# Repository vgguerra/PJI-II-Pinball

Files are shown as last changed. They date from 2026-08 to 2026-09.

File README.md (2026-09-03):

# PJI-II Pinball IFSC

Documentação técnica do pinball desenvolvido na disciplina de Projeto Integrador II do curso de
Engenharia de Telecomunicações do IFSC, Campus São José.

Este repositório dá continuidade ao trabalho da turma anterior. O foco aqui é registrar o que
existe, como está ligado, por que foi feito dessa forma e o que ainda falta, de modo que quem
assumir o projeto não precise reconstruir esse entendimento a partir do esquemático.

## Estado atual

O pinball ainda não está funcional. A etapa anterior entregou a arquitetura eletrônica (esquemático
e simulação), as classes básicas de acesso ao hardware em Python e boa parte das peças mecânicas
impressas em 3D. A lógica de jogo não foi implementada.

| Frente | Situação |
|---|---|
| Mecânica (estrutura, flippers, bumpers, injetor) | Parcial: gabinete e playfield decorado prontos, sem componentes instalados |
| Hardware (esquemático e simulação Proteus) | A refazer: o esquemático anterior tem erros estruturais e nada foi montado |
| Software (acesso ao hardware) | Parcial: classes `Raspberry` e `Pcf8574` funcionando |
| Software (lógica do jogo) | Não iniciado |
| Montagem e integração final | Não iniciado |

### A mesa em 13/08/2026

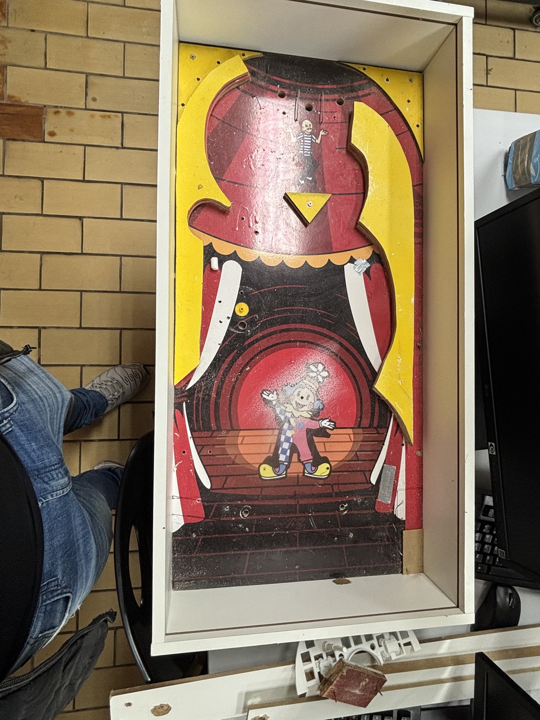
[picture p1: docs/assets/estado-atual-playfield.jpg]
Estado atual do playfield


O gabinete está pronto e o playfield está decorado, com a arte montada em camadas de MDF recortadas.
Estão instaladas as guias de bola brancas, um poste amarelo e alguns reforços, e os furos de montagem
já existem: três maiores no arco superior, dois com anel na região dos flippers e vários de parafuso
ao longo das bordas. A caixa mede 45 x 90 cm.

Não há nenhuma eletrônica instalada: nenhum sensor, solenoide, LED, fio, conector ou placa. A
eletrônica do projeto anterior nunca saiu do papel.

Vale destacar também um erro no esquemático: os três expansores PCF8574 estão com os pinos de
endereço interligados e aterrados, o que os coloca todos em `0x20`. Isso é provavelmente a causa das
falhas intermitentes de comunicação relatadas no relatório anterior. O diagnóstico está em
[Pendências, item P1](docs/09-pendencias-e-roadmap.md).

## Documentação

| Documento | Conteúdo |
|---|---|
| [01. Visão geral](docs/01-visao-geral.md) | Objetivo, escopo, decisões de arquitetura e glossário |
| [02. Arquitetura de hardware](docs/02-arquitetura-hardware.md) | Topologia do sistema, barramentos e alimentação |
| [03. Componentes](docs/03-componentes.md) | Cada componente do projeto, o que é e como é usado |
| [04. Circuitos integrados](docs/04-circuitos-integrados.md) | PCF8574 e L293D em detalhe |
| [05. Pinagem e mapa de I/O](docs/05-pinout.md) | Tabelas pino a pino de todos os CIs |
| [06. Software](docs/06-software.md) | Estrutura do código, API das classes e como evoluir |
| [07. Mecânica](docs/07-mecanica.md) | Peças 3D, modelos de referência e processo |
| [08. Simulação no Proteus](docs/08-simulacao-proteus.md) | Como abrir e rodar a simulação |
| [09. Pendências e roadmap](docs/09-pendencias-e-roadmap.md) | Erros conhecidos e próximos passos |

## Arquitetura em uma figura

```mermaid
flowchart LR
    subgraph SENS["Sensoriamento"]
        SI["3x sensor indutivo<br/>LJ12A3-4-Z/BX<br/>(detecta a bola)"]
        CF["10x fim de curso<br/>KW11-3Z-3<br/>(alvos e posições)"]
    end

    subgraph CTRL["Controle"]
        RPI["Raspberry Pi 4<br/>16 GPIOs de entrada<br/>e barramento I2C1"]
    end

    subgraph EXP["Expansão de I/O"]
        U1["U1, PCF8574"]
        U2["U2, PCF8574"]
        U3["U3, PCF8574"]
    end

    subgraph ACT["Atuação"]
        SL["10x solenoide<br/>(flippers e bumpers)"]
        DRV["3x L293D<br/>driver de potência"]
        LED["12x LED vermelho<br/>(iluminação cênica)"]
    end

    SI -->|nível lógico| RPI
    CF -->|nível lógico| RPI
    RPI <-->|"I2C (SDA/SCL)"| U1
    RPI <-->|"I2C (SDA/SCL)"| U2
    RPI <-->|"I2C (SDA/SCL)"| U3
    U1 --> SL
    U2 --> SL
    U2 --> DRV
    U3 --> DRV
    DRV --> LED
```

A Raspberry Pi lê os sensores diretamente pelos GPIOs, o que mantém a latência baixa (importante
para os flippers), e comanda as cargas através de três expansores PCF8574 no barramento I²C, porque
a Pi não tem GPIOs suficientes para tudo. Os PCF8574 não fornecem corrente para acionar cargas, e é
aí que entram os L293D.

## Ferramentas

`tools/levantar_entradas.py` descobre qual sensor está ligado a qual GPIO, que é a pendência que
trava o resto do projeto. Roda na Raspberry Pi:

```bash
python3 tools/levantar_entradas.py monitor       # imprime toda mudança de estado
python3 tools/levantar_entradas.py identificar   # pede um sensor por vez e grava mapeamento.csv
```

## Organização do repositório

```
PJI-II-Pinball/
├── docs/                   documentação técnica
│   ├── 01-visao-geral.md
│   ├── ...
│   └── assets/             imagens e recortes do esquemático
├── mecanica/
│   └── modelos-3d/         modelos paramétricos em OpenSCAD
├── tools/
│   └── levantar_entradas.py    levantamento do mapeamento sensor para GPIO
├── upstream/
│   └── pinball/            submódulo apontando para o repositório anterior
└── README.md
```

### Sobre o `upstream/pinball`

O trabalho da etapa anterior não foi copiado para cá. Ele está referenciado como submódulo Git
apontando para o repositório original,
[danieCFernandes/pinball](https://github.com/danieCFernandes/pinball), que contém o código-fonte, o
esquemático do Proteus e o relatório final daquela etapa.

Dessa forma o histórico e a autoria originais ficam preservados, e no GitHub a pasta
`upstream/pinball` aparece como um link direto para aquele repositório em vez de abrir uma árvore
de arquivos.

Para clonar este repositório junto com o conteúdo do submódulo:

```bash
git clone --recurse-submodules https://github.com/vgguerra/PJI-II-Pinball.git
```

Se você já clonou sem o `--recurse-submodules`:

```bash
git submodule update --init --recursive
```

Para atualizar a referência caso o repositório original receba novos commits:

```bash
git submodule update --remote upstream/pinball
git add upstream/pinball && git commit -m "Update upstream pinball reference"
```

## Créditos

Etapa anterior (2025/2), projeto de hardware, mecânica e drivers de software: Daniel Cardoso
Fernandes e Roberto da Silva Espindola. Orientação do Prof. Adilson Jair Cardoso.

Instituto Federal de Santa Catarina, Campus São José. Engenharia de Telecomunicações, Projeto
Integrador II.

## Licença

O repositório da etapa anterior declara a MIT License no README, mas não inclui o arquivo `LICENSE`.

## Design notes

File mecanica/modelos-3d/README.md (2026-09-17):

# Modelos 3D

Modelos em [OpenSCAD](https://openscad.org/) para os mecanismos do pinball. Todas as medidas estão
em milímetros e ficam no início de cada arquivo, ou num `parameters.scad` próprio, para serem
ajustadas antes de imprimir.

| Mecanismo | Pasta | Situação |
|---|---|---|
| Flipper | [`flipper`](flipper/) | versão 5, com os dois lados exportados |
| Drop target | [`drop-target`](drop-target/README.md) | peças convertidas dos STL de referência, com simulação do ciclo |
| Plunger handle | [`pinball-plunger`](pinball-plunger/README.md) | impresso e em ajuste de encaixe |

## Flipper

[`flipper/flipper-v5.scad`](flipper/flipper-v5.scad) é a versão atual e reúne o mecanismo completo de
90 mm: pá com canal para borracha, eixo sextavado de 8 mm, base com mancal e batentes, alavanca
inferior, guia frontal, haste de acionamento e botão.

É o único arquivo do flipper: a versão anterior, só do lado esquerdo, foi removida.

O mesmo arquivo atende os dois lados da mesa. Em `lado_flipper`, `"esquerdo"` ou `"direito"` já
ajusta junto as três medidas que mudam com a assimetria do gabinete:

| | esquerdo | direito |
|---|---:|---:|
| Distância lateral | 95,0 mm | 127,0 mm |
| Curso da haste | 110,0 mm | 142,0 mm |
| Posição da guia em X | −55,0 mm | −87,0 mm |

O arquivo abre na montagem, que roda em **View > Animate**. Para inspecionar ou exportar uma peça,
altere `modo_visualizacao` para `"flipper"`, `"eixo"`, `"base"`, `"alavanca"`, `"haste"`,
`"guia_frontal"` ou `"botao"` — as sete peças do mecanismo, cada uma isolada. O modo
`"mesa_impressao"` deita cinco delas na posição de impressão, para fatiar de uma vez; a pá e o eixo
ficam de fora porque pedem orientação própria.

Os STL já exportados estão separados por lado em
[`flipper/export/lado_esquerdo`](flipper/export/lado_esquerdo/) e
[`flipper/export/lado_direito`](flipper/export/lado_direito/), com as sete peças em cada: `alavanca`,
`base`, `botao`, `eixo`, `flipper`, `guia_frontal` e `haste`.

## Drop target

O diretório [`drop-target`](drop-target/README.md) tem as três peças imprimíveis convertidas para
OpenSCAD a partir dos STL de referência, com a caixa envolvente idêntica à do original:

| Peça | Envelope |
|---|---:|
| Gaiola | 40 × 85 × 47,5 mm |
| Alvo | 38,4 × 80 × 12,5 mm |
| Braço do servo | 12 × 64,8 × 4 mm |

Os STL prontos para fatiar ficam em [`drop-target/print`](drop-target/print/README.md) e os originais
que serviram de referência em `drop-target/references`, junto com a foto do conjunto montado.

[`drop-target/simulation`](drop-target/simulation/README.md) monta um módulo completo, com servo
SG90, micro-switch e cordão, para conferir o ciclo antes de repetir o conjunto três vezes: a bola
derruba o alvo, o micro-switch abre, o servo recolhe o braço e o cordão levanta o alvo de volta.
O movimento roda em **View > Animate**.

## Plunger handle

O diretório [`pinball-plunger`](pinball-plunger/README.md) tem o pegador do lançador. O corpo externo
vem do STL de referência sem alteração; o interior foi refeito para a haste real de 6,1 mm e para um
parafuso M4 × 10 que trava a haste.

O furo do parafuso é cônico, de 4,20 mm na entrada a 3,80 mm no fundo: o parafuso começa a descer
solto e vai apertando conforme avança. Essa peça já foi impressa uma vez e as medidas atuais vieram
desse teste.

## Como usar

1. Abra o `.scad` do mecanismo no OpenSCAD.
2. `F5` para visualizar, `F6` para renderizar de verdade.
3. Onde houver animação, ative **View > Animate**; ela usa a variável `$t`.
4. Para exportar, selecione a peça no modo de visualização, renderize com `F6` e use
   **File > Export > Export as STL**.

Pela linha de comando, o que evita abrir a interface:

```bash
openscad --export-format binstl -o saida.stl arquivo.scad
```

## Antes de imprimir

Confira as folgas na sua impressora antes de mandar o conjunto todo. Furo em FDM sai menor que o
nominal, e foi exatamente isso que inutilizou a primeira impressão do plunger: o encaixe desenhado
com 6,00 mm não aceitou uma haste de 6,10 mm. Meça uma peça de teste, compare com o nominal e ajuste
o parâmetro de folga antes de gastar filamento na peça inteira.

As medidas de eixo, espessura do playfield e curso dos mecanismos ainda precisam ser validadas no
protótipo físico.

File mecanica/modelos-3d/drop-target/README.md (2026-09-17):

# Drop target

Conversão para OpenSCAD das três peças do drop target de
[Chris Mitchell](https://www.thingiverse.com/thing:2772610), cujos STL estão em
[`references/`](references/). A foto [`references/image.jpg`](references/image.jpg) mostra o
conjunto montado: **três impressões de cada arquivo**.

Cada peça foi remodelada a partir da malha original, e não apenas importada, para permitir edição
no OpenSCAD. Os STL de referência continuam intactos e podem ser impressos como estão.

| Peça | Arquivo | Envelope | Volume × STL |
|---|---|---|---:|
| Gaiola | [`cage.scad`](cage.scad) | 40 × 85 × 47,5 mm | +0,01 % |
| Alvo | [`target.scad`](target.scad) | 38,4 × 80 × 12,5 mm | +0,00 % |
| Braço do servo | [`servo_stick.scad`](servo_stick.scad) | 12 × 64,8 × 4 mm | −0,04 % |

A caixa envolvente de cada peça convertida é idêntica à do STL correspondente; a diferença de
volume vem apenas da quantidade de facetas nos furos redondos.

## Como ajustar o tamanho peça a peça

Tudo fica em [`parameters.scad`](parameters.scad). Para mudar só uma peça, use a escala dela:

```scad
target_scale = [1, 1.2, 1];   // alvo 20 % mais comprido, gaiola e braço intactos
cage_scale = [1, 1, 1];
servo_stick_scale = [1, 1, 1];
```

Para mudanças que não são de escala, edite as medidas nomeadas: espessura das laterais
(`cage_wall`), vão da gaiola (`cage_slot_width`), largura e comprimento do alvo (`target_width`,
`target_length`), espessura da cabeça (`target_head_thickness`), diâmetro dos furos
(`cage_screw_diameter`, `cage_pin_diameter`, `target_knot_hole_diameter`) e assim por diante. Os
contornos das peças são listas de pontos com nome, então dá para mover um vértice específico sem
mexer no resto.

A quantidade de cada peça também é parâmetro: `cage_count`, `target_count` e `servo_stick_count`,
todos em 3 para reproduzir a foto.

## Como o mecanismo funciona

O alvo corre encostado na face traseira da gaiola. As orelhas de 4,2 mm passam atrás das duas
laterais e é isso que prende o alvo contra a estrutura; a metade dianteira da cabeça entra no vão de
31 mm e faz a guia. O curso é de 30 mm, exatamente a altura da cabeça: em baixo, a base do alvo
encosta na base da gaiola e o topo da cabeça fica rente ao topo da estrutura, ou seja, o alvo some
sob o playfield; em cima, a cabeça aparece inteira. Essa posição foi achada testando peça contra
peça, e é a única em que não há interferência em nenhum ponto do curso.

O microservo é representado na montagem nas coordenadas da gaiola ainda deitada. O eixo fica na
lateral direita, normal à parede, e o corpo do SG90 fica apoiado nessa lateral. O horn e o braço
impresso entram no vão e giram no plano vertical imediatamente abaixo do alvo. Os dois braços
compartilham o mesmo eixo e giram juntos.

O fio é amarrado na ponta longa do braço, a aproximadamente 42 mm do eixo, e sobe até o furo do bloco
do alvo. É essa ponta que sobe junto com o alvo: o braço gira e puxa o fio, levantando o alvo; no
sentido contrário, o alvo desce. Com o fio esticado, a simulação resolve o triângulo a cada quadro
para manter os dois pontos conectados durante os 30 mm de curso.

O dente inferior do alvo encosta na alavanca do microswitch quando o alvo está levantado. Quando a
bola derruba o alvo, o dente desce e o contato abre. A animação segue essa lógica: os três alvos
caem em momentos diferentes e, depois que o terceiro cai, os três servos rearmam o banco junto.

## Vistas

[`drop-target.scad`](drop-target.scad) é o arquivo de abertura. Em `view_mode`:

- `"unidade"`: uma unidade completa em pé, recomendada para conferir o encaixe;
- `"banco"`: três gaiolas encostadas, uma a cada 40 mm, com alvo, servo, chave, fio e braço;
- `"mesa"`: o banco instalado sob o playfield de 450 × 900 mm, com as aberturas dos alvos;
- `"impressao"`: as peças deitadas na quantidade pedida, como saem da impressora;
- `"gaiola"`, `"alvo"`, `"braco_servo"`, `"servo"`: uma peça isolada.

`target_state` aceita `"levantado"`, `"baixado"` e `"animado"`. Para ver o ciclo completo, deixe
`"animado"` e ative **View > Animate** no OpenSCAD. O ritmo fica em `target_drop_times`,
`target_drop_duration`, `reset_start` e `reset_duration`.

O microservo, o microswitch e o playfield são envelopes de referência para conferir encaixe e curso,
não peças para imprimir. As três peças impressas continuam sendo gaiola, alvo e braço.

## O que ficou como estimativa

O conjunto de STL não traz suporte de servo nem nada que fixe a posição relativa das peças. A
posição do alvo (`target_depth_offset`, `target_drop_offset`, `target_travel`) veio de teste de
interferência e não tem folga sobrando. Já a posição do servo (`servo_shaft`), o comprimento do fio
(`string_length`) e o ponto de amarração (`servo_stick_tie`) foram escolhidos para dar o curso
inteiro sem o braço bater no alvo nem na gaiola, o que foi conferido em todo o curso, mas precisam
ser confirmados com o servo real na mão. O mesmo vale para a chave: os dois furos de 2 mm da lateral
direita são os que já existem na peça, mas o alcance da alavanca depende do modelo de microswitch.

A altura em que o banco fica sob a mesa também é escolha de montagem: o topo da estrutura encosta na
face inferior do playfield, e com 10 mm de espessura sobram 20 mm de alvo acima da superfície.

As abas de fixação do servo têm 32,2 mm e o vão entre as laterais tem 31 mm, então elas encostam nas
duas paredes. Pela geometria é o que segura o servo no lugar, mas na montagem real pode ser preciso
lixar as abas ou abrir um rebaixo.

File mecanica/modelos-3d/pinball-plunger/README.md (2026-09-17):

# Plunger handle

Handle do lançador de bolinhas do pinball. O corpo externo vem de
[`ref/Pinball_Plunger_Handle_v5.stl`](ref/Pinball_Plunger_Handle_v5.stl) sem nenhuma alteração; o que
mudou foi o interior, refeito para a haste e o parafuso que vamos usar.

## Arquivos

- [`pinball-plunger-handle.scad`](pinball-plunger-handle.scad): importa a referência e refaz o encaixe interno;
- [`print/pinball-plunger-handle.stl`](print/pinball-plunger-handle.stl): gerado a partir do `.scad`, pronto para fatiar;
- [`ref/Pinball_Plunger_Handle_v5.stl`](ref/Pinball_Plunger_Handle_v5.stl): referência original, não mexer.

## O que a referência tem por dentro

A referência é um desenho em polegadas e não serve para a nossa haste:

| Item | Referência | Nosso arquivo |
|---|---:|---:|
| Envelope | 31,75 × 53,97 × 31,75 mm | igual |
| Diâmetro externo da base | 25,40 mm (1") | igual |
| Furo axial | 13,21 mm (0,52") × 12,75 mm | 7,00 mm × 34,00 mm |
| Furo do parafuso | 2,38 mm (3/32") | cônico, 4,20 → 3,80 mm |
| Assento plano | não tem | 9,00 × 0,60 mm |

## Medidas do nosso arquivo

| Item | Medida |
|---|---:|
| Diâmetro da haste | 6,10 mm (medido na peça) |
| Folga diametral | 0,90 mm |
| Encaixe da haste | 7,00 mm × 34,00 mm |
| Chanfro de entrada | 14,00 mm, 4,00 mm de profundidade |
| Furo do parafuso, entrada | 4,20 mm |
| Furo do parafuso, fundo | 3,80 mm |
| Profundidade do furo | 7,78 mm |
| Assento plano no topo | 9,00 × 0,60 mm |
| Centro do furo do parafuso | 6,35 mm da face de entrada |
| Do assento até a haste | 8,68 mm |
| Parafuso | M4 × 10 mm |
| Volume | 24,7 cm³ |

O furo antigo de 13,21 mm é tapado e o encaixe novo de 7,00 mm é aberto no lugar, com 34 mm de
profundidade. O chanfro de entrada de 14 mm guia a haste e, de quebra, tira da face frontal a borda
do furo original, que era o que sujava a malha na boca do encaixe.

## Como a haste fica presa

O furo do parafuso desce do topo da base e **entra no encaixe da haste**: a ponta do parafuso aperta
a haste contra o fundo do furo, e é esse aperto que prende as duas peças. Na referência o furinho de
3/32" já fazia esse caminho.

**O furo é cônico.** Entra com 4,20 mm no assento e fecha até 3,80 mm lá embaixo, junto ao encaixe
da haste, ao longo de 7,78 mm. São 0,4 mm de fechamento, pouco menos de 3° de ângulo incluso.

Na prática, descendo o parafuso:

| Profundidade | Diâmetro | O que acontece |
|---|---:|---|
| 0 a 3,9 mm | 4,20 a 4,00 mm | desce solto, sem esforço |
| 3,9 mm | 4,00 mm | encosta nas paredes |
| 3,9 a 7,8 mm | 4,00 a 3,80 mm | vai mordendo, aperto crescente |
| 7,8 mm | 3,80 mm | 0,10 mm de interferência no raio |

A partida é fácil e o esforço só aparece no fim, quando já falta pouco: é o oposto do furo estreito
de ponta a ponta, que exigia força máxima logo no primeiro giro e espanava a cabeça. E, diferente do
furo reto de 4,0 mm, aqui existe aperto de verdade nas últimas voltas.

O aperto final é leve — 0,10 mm no raio é cerca de um quarto da profundidade do filete de um M4.
Segura o parafuso no lugar e gera alguma pressão, mas não é o mesmo que uma rosca cheia. Se quiser
mais mordida, baixe `screw_end_diameter` para 3,6 ou 3,5; a entrada continua fácil do mesmo jeito,
porque quem manda na partida é `screw_entry_diameter`.

**Recomendação que continua valendo:** faça uma marca de punção ou um rebaixo raso na haste, no ponto
onde a ponta do parafuso encosta. Com o cone o parafuso já fica firme, mas o que garante que a haste
não escorrega no tranco do plunger é a ponta assentada numa depressão, e não o atrito. Para achar o
ponto: monte a haste até o fundo, desça o parafuso e gire até riscar. Fica a 6,35 mm da face de
entrada.

Do fundo do assento até a haste são 8,68 mm, então o parafuso precisa ser **mais longo que isso**:
um M4 de 10 mm encosta com 1,3 mm de sobra; um de 8 mm não chega a tocar. Essa conta já considera o
pior caso, com a haste empurrada para o fundo do encaixe pelo próprio parafuso.

O assento plano de 9 mm no topo tem duas funções: a ponta do parafuso não escorrega na curvatura da
base ao começar a entrar, e a cabeça de 8 mm de um M4 cabeça panela apoia reta nele. Com parafuso
sem cabeça, o assento serve só de guia.

### Parafuso para comprar

Serve qualquer **M4 × 10 mm**, de preferência com cabeça, que é bem mais fácil de rosquear no
plástico do que um sem cabeça:

- cabeça panela Phillips, avulso, na [Casa do Resistor](https://www.casadoresistor.com.br/parafuso-m4x10-cabeca-panela-philips) — cerca de R$ 0,42 a unidade;
- o mesmo parafuso em pacote de 50 ou 100 peças na [Leroy Merlin](https://www.leroymerlin.com.br/50-pc-parafuso-maquina-cabeca-panela-phillips-m4-4mm-x-10mm_1570865961) e no [Mercado Livre](https://produto.mercadolivre.com.br/MLB-1543465019-parafuso-maquina-cabeca-panela-phillips-m4-x-10mm-100-pecas-_JM);
- se preferir que nada fique para fora, [Allen sem cabeça M4 × 10 de ponta cônica](https://www.mercadolivre.com.br/parafuso-allen-sem-cabeca-m4-x-10--100-pecas--aco-129/up/MLBU747480122): a ponta crava na haste e segura melhor, mas exige chave allen de 2 mm e mais força para entrar.

## Histórico das decisões

O furo do parafuso passou por várias versões antes de chegar no cone, e vale registrar o porquê de
cada uma ter sido descartada:

| Versão | Por que não ficou |
|---|---|
| 3,30 mm reto | medida de furo para macho M4; sem a ferramenta o parafuso não entra |
| Rosca M4 modelada no arquivo | passo de 0,70 mm é fino demais para FDM reproduzir, ainda mais com o furo deitado |
| 3,50 mm reto | força máxima logo no primeiro giro, risco de espanar a cabeça |
| 4,30 → 3,50 mm em dois degraus | resolvia o esforço, mas o degrau não era desejado |
| 4,00 mm reto | entra fácil, mas não gera aperto nenhum |
| **4,20 → 3,80 mm cônico** | partida livre e aperto progressivo — é o que está no arquivo |

Se um dia o aperto do cone não bastar, o caminho mais firme é insert térmico M4: troque
`screw_entry_diameter` e `screw_end_diameter` por um furo reto de 5,6 mm, que cabe nos 7,78 mm de
parede e dá rosca de metal.

## Impressão

Imprimir com a boca do encaixe voltada para cima, para não precisar de suporte dentro do furo.
0,20 mm de camada, 4 paredes e pelo menos 30% de preenchimento.

O encaixe da haste está em 7,00 mm para uma haste de 6,10 mm. A folga é grande de propósito: furo em
FDM sai menor que o nominal, e a primeira impressão, feita com 6,00 mm, não aceitou a haste. A conta
do comprimento do parafuso já leva em conta essa folga. Se quiser apertar o encaixe depois de medir
a peça impressa, mexa em `rod_clearance`.

Para regerar o STL depois de mexer em alguma medida:

```bash
openscad --export-format binstl -o print/pinball-plunger-handle.stl pinball-plunger-handle.scad
```

O `.scad` importa a referência por caminho relativo, então rode o comando de dentro desta pasta.
A renderização leva uns 15 s porque a malha importada tem 22.922 triângulos.

O furo do parafuso é impresso deitado nessa orientação e sai com a leve deformação típica de furo
horizontal em FDM. Medindo a primeira impressão, a máquina fechou só 0,04 mm em relação ao nominal,
então o cone deve sair em torno de 4,16 na entrada e 3,76 no fundo — a partida continua folgada e o
aperto final fica um pouco maior que o desenhado.

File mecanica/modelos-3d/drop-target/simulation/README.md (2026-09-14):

# Simulação de um drop target

`drop-target-simulation.scad` monta **um único módulo completo** para validar o
movimento antes de repetir o conjunto três vezes.

O conjunto usa as peças convertidas a partir dos STL de referência:

- `cage.scad`: gaiola;
- `target.scad`: alvo amarelo;
- `servo_stick.scad`: braço plástico que encaixa no eixo do SG90.

O servo e o micro-switch são envelopes de componentes comerciais. A esfera é
um elemento visual de teste: ela toca a cabeça amarela e inicia a queda. O
OpenSCAD não é um solver físico; por isso o ciclo é cinemático, mas foi
montado com a sequência mecânica do protótipo:

```text
esfera atinge o alvo
  -> alvo desce 30 mm
  -> cordão fica frouxo e o micro-switch libera
  -> servo retorna o braço ao ponto de tração
  -> cordão tensiona e o alvo sobe
```

## Como animar

Abra `drop-target-simulation.scad` no OpenSCAD e use **View > Animate**. A
vista padrão é `view_mode = "modulo"`, que mostra o mecanismo sem o tamanho
do playfield atrapalhar a inspeção. Para conferir a instalação sob a mesa,
use:

```scad
view_mode = "mesa";
```

Estados fixos úteis:

```scad
target_state = "levantado";
target_state = "baixado";
target_state = "animado";
```

Os principais ajustes estão no início do arquivo: `simulation_servo_shaft`,
`arm_rest_angle`, `cord_sag`, `impact_time`, `reset_start`,
`drop_duration`, `release_duration` e `reset_duration`. O eixo foi colocado em
`[6, -54.5, 31]` no sistema da gaiola:
o corpo do SG90 fica deitado dentro da janela lateral esquerda, o eixo aponta
para cima e o braço entra no vão na horizontal. A ponta fina do braço longo
fica à frente e abaixo do alvo, próxima do ponto de amarração. Ao instalar o
primeiro servo real, esse é o primeiro ponto a conferir.

O alvo sobe pela abertura de aproximadamente 30 x 10 mm do playfield de
450 x 900 mm. O mecanismo completo permanece abaixo do playfield; somente a
cabeça amarela atravessa a abertura.

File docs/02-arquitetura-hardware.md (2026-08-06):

[Voltar ao índice](../README.md)

# 02. Arquitetura de hardware

## 2.1 Esquemático completo

O esquemático original está no projeto Proteus `hardware/diagrama-pinball.pdsprj` do repositório
anterior (acessível por [`upstream/pinball`](../upstream/pinball)). A figura abaixo é a exportação
que acompanha aquele repositório.

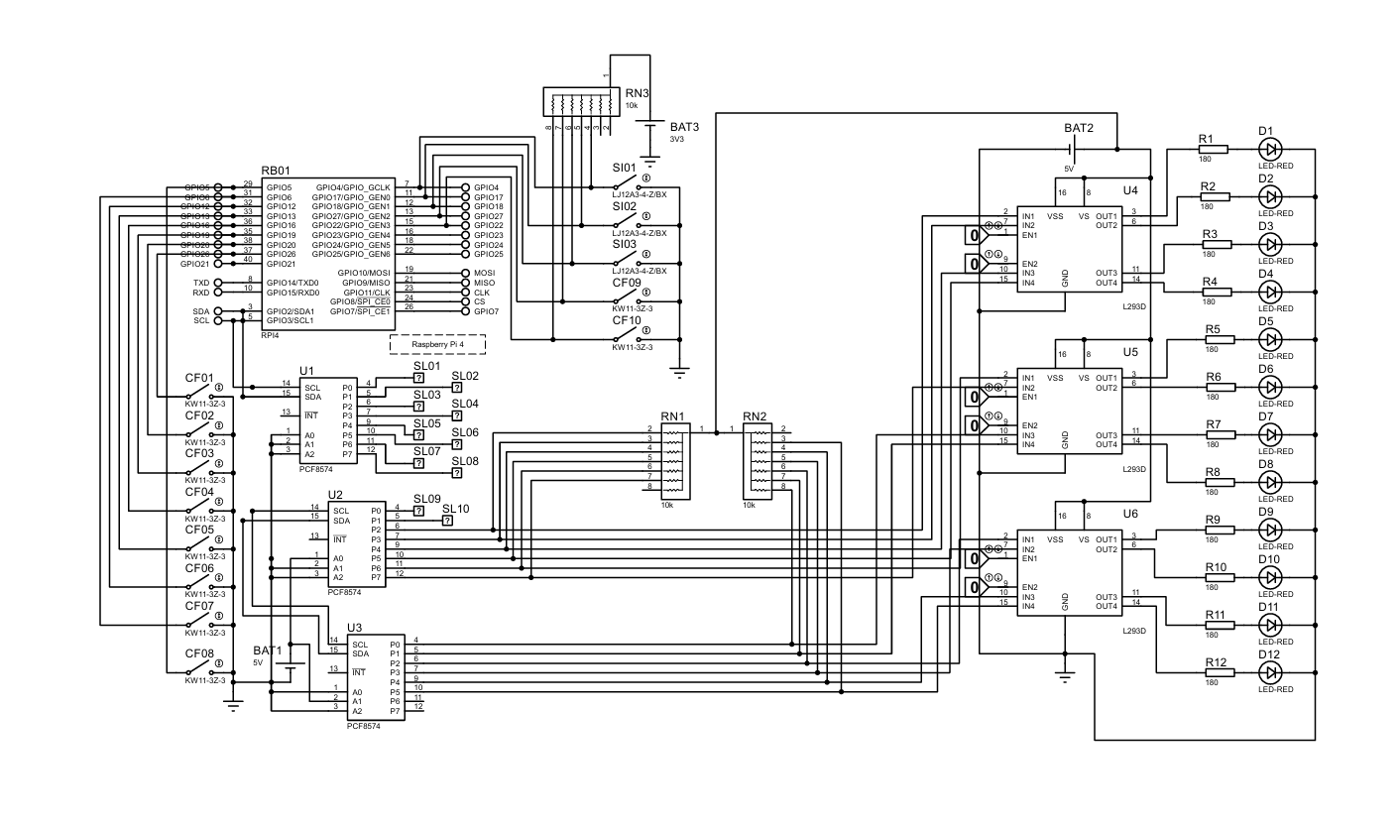
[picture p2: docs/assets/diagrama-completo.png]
Esquemático completo do pinball


O esquemático se lê da esquerda para a direita em quatro blocos: as entradas (chaves de fim de curso
CF01 a CF08), o controlador (RB01, a Raspberry Pi 4) com os sensores do topo, os expansores de I/O
(U1, U2 e U3) e, à direita, o estágio de potência (U4, U5 e U6) com a carga de LEDs.

## 2.2 Topologia do sistema

```mermaid
flowchart TB
    subgraph POT["Alimentação"]
        B3["BAT3, 3V3<br/>referência dos pull-ups<br/>de entrada"]
        B1["BAT1, 5V<br/>lógica dos PCF8574"]
        B2["BAT2, 5V<br/>potência dos L293D"]
    end

    subgraph ENTRADAS["Entradas digitais, 13 sensores"]
        CF1["CF01 a CF08<br/>fim de curso<br/>alvos e botões"]
        SI["SI01 a SI03<br/>sensor indutivo<br/>presença da bola"]
        CF2["CF09 e CF10<br/>fim de curso"]
        RN3["RN3, rede 10k<br/>pull-up"]
    end

    RPI["<b>RB01, Raspberry Pi 4</b><br/>16 GPIOs configurados como entrada<br/>I2C1 em GPIO2 (SDA) e GPIO3 (SCL)"]

    subgraph I2C["Barramento I2C1"]
        U1["<b>U1, PCF8574</b><br/>P0 a P7<br/>8 solenoides"]
        U2["<b>U2, PCF8574</b><br/>P0 e P1: 2 solenoides<br/>P2 a P7: comando dos drivers"]
        U3["<b>U3, PCF8574</b><br/>P0 a P7<br/>comando dos drivers"]
    end

    subgraph SAIDAS["Saídas"]
        SL["SL01 a SL10<br/>10 solenoides"]
        RN12["RN1 e RN2<br/>redes 10k"]
        U456["U4, U5, U6<br/>3x L293D<br/>12 canais de potência"]
        LEDS["D1 a D12 com R1 a R12 (180R)<br/>12 LEDs vermelhos"]
    end

    B3 --> RN3
    RN3 --> SI
    RN3 --> CF2
    CF1 --> RPI
    SI --> RPI
    CF2 --> RPI
    RPI <--> U1
    RPI <--> U2
    RPI <--> U3
    B1 --> U1
    B1 --> U2
    B1 --> U3
    U1 --> SL
    U2 --> SL
    U2 --> RN12
    U3 --> RN12
    RN12 --> U456
    B2 --> U456
    U456 --> LEDS
```

## 2.3 Contagem de I/O

Este é o balanço que justifica a existência dos expansores.

| Função | Quantidade | Onde está ligado |
|---|---|---|
| Sensores de fim de curso | 10 (CF01 a CF10) | GPIO direto da Raspberry Pi |
| Sensores indutivos | 3 (SI01 a SI03) | GPIO direto da Raspberry Pi |
| Solenoides | 10 (SL01 a SL10) | U1 completo, mais P0 e P1 de U2 |
| Canais de LED | 12 (D1 a D12) | U4, U5 e U6, comandados por U2 e U3 |

Somando: 13 entradas nos GPIOs e 22 pontos de saída atendidos por 24 pinos de expansor. A Raspberry
Pi sozinha não daria conta das duas coisas, o que valida a decisão de expandir.

## 2.4 Barramento I²C

A comunicação usa o `I2C1` da Raspberry Pi, disponível nos pinos físicos 3 e 5:

| Sinal | GPIO (BCM) | Pino físico | Destino |
|---|---|---|---|
| SDA | GPIO2 | 3 | Pino 15 (SDA) de U1, U2 e U3 |
| SCL | GPIO3 | 5 | Pino 14 (SCL) de U1, U2 e U3 |

Os três PCF8574 compartilham o mesmo par de fios. O que deveria diferenciá-los é o endereço,
configurado nos pinos de seleção A0, A1 e A2 de cada CI.

> **Atenção.** No esquemático, os pinos A0, A1 e A2 dos três PCF8574 estão todos ligados no mesmo
> nó, e esse nó vai ao terra. Isso faz com que os três CIs respondam no endereço `0x20`
> simultaneamente, o que é um conflito de barramento. O diagnóstico completo e a correção estão em
> [09. Pendências, item P1](09-pendencias-e-roadmap.md). Trate as atribuições de U1, U2 e U3 nesta
> documentação como a intenção do projeto, não como algo que funcione da forma como está desenhado.

O esquemático também não mostra resistores de pull-up externos em SDA e SCL. Na prática a Raspberry
Pi tem pull-ups de 1,8k internos nesses dois pinos, o que costuma ser suficiente para trechos
curtos. Como o cabeamento dentro de uma mesa de pinball é longo e passa perto de solenoides, isso
merece verificação. Ver [P5](09-pendencias-e-roadmap.md).

## 2.5 Alimentação

O esquemático usa três fontes, representadas como baterias por ser um ambiente de simulação.

| Fonte | Tensão | O que alimenta |
|---|---|---|
| BAT1 | 5 V | Alimentação lógica dos três PCF8574 |
| BAT2 | 5 V | Pinos VSS (lógica) e VS (potência) dos três L293D |
| BAT3 | 3,3 V | Referência da rede de pull-up RN3, nas entradas de sensor |

A escolha de 3,3 V para RN3 é correta e importante: os GPIOs da Raspberry Pi trabalham em 3,3 V e
não são tolerantes a 5 V. Puxar uma entrada para 5 V danificaria o SoC.

Já os PCF8574 estão em 5 V, o que cria uma questão de compatibilidade de níveis no barramento I²C
que precisa ser resolvida antes da montagem. Está registrado em
[P4](09-pendencias-e-roadmap.md).

Uma observação sobre dimensionamento: o esquemático não contempla a fonte das solenoides. Solenoides
de pinball tipicamente operam entre 24 V e 48 V e consomem alguns ampères em pulsos curtos. Isso
demanda uma fonte separada, e o estágio de acionamento precisa ser compatível com essa tensão.
Está registrado em [P2](09-pendencias-e-roadmap.md).

## 2.6 Caminho de sinal, entrada

```mermaid
flowchart LR
    A["Bola de metal<br/>ou alvo mecânico"] --> B["Sensor<br/>indutivo ou fim de curso"]
    B --> C["Rede de pull-up<br/>RN3 10k em 3V3<br/>ou pull-up interno"]
    C --> D["GPIO da Raspberry Pi<br/>configurado como entrada"]
    D --> E["GPIO.input()<br/>no Python"]
```

Todos os sensores são ligados em configuração de contato para o terra. O contato em repouso está
aberto, e o pull-up mantém a entrada em nível alto. Quando o sensor atua, ele fecha o caminho para
o terra e a entrada vai a nível baixo.

Consequência prática para o software: a lógica é invertida. `GPIO.input(pin) == 0` significa sensor
acionado, e `== 1` significa sensor em repouso. Isso é o padrão em circuitos de contato seco e é
mais imune a ruído do que a alternativa, mas precisa estar explícito no código.

## 2.7 Caminho de sinal, saída

Há dois caminhos distintos de saída, e a diferença entre eles importa.

O primeiro caminho vai para as solenoides. As saídas P0 a P7 de U1 e P0 e P1 de U2 vão diretamente
para SL01 a SL10. No esquemático essas solenoides aparecem como componentes sem modelo atribuído,
que é a forma do Proteus indicar um símbolo genérico ainda não definido. Ou seja, o estágio de
acionamento das solenoides ainda não foi projetado.

```mermaid
flowchart LR
    A["Software chama<br/>pcf.aciona_saida(n)"] --> B["Escrita I2C<br/>write_byte"]
    B --> C["Pino Pn do PCF8574<br/>vai a nível baixo"]
    C --> D["SL01 a SL10<br/>estágio de potência<br/>ainda não definido"]
    D --> E["Solenoide empurra a bola"]
```

O segundo caminho vai para os LEDs, e este está completo no esquemático. As saídas P2 a P7 de U2 e
P0 a P7 de U3 alimentam as entradas IN1 a IN4 dos três L293D. Cada saída OUT do L293D passa por um
resistor de 180 ohms e acende um LED vermelho.

```mermaid
flowchart LR
    A["Software chama<br/>pcf.aciona_saida(n)"] --> B["Escrita I2C"]
    B --> C["Pino Pn do PCF8574"]
    C --> D["Entrada INn do L293D<br/>via rede RN1 ou RN2"]
    D --> E["Saída OUTn<br/>meia-ponte chaveada"]
    E --> F["Resistor de 180R"]
    F --> G["LED vermelho D1 a D12"]
```

## 2.8 As redes resistivas

O esquemático usa três redes resistivas de 8 elementos com terminal comum, referência `RES8SIPB`.
São encapsulamentos SIP que agrupam oito resistores iguais, usados para economizar espaço quando
várias linhas precisam do mesmo resistor.

| Rede | Valor | Onde está |
|---|---|---|
| RN1 | 10 kΩ | Entre as saídas dos PCF8574 e as entradas dos L293D |
| RN2 | 10 kΩ | Entre as saídas dos PCF8574 e as entradas dos L293D |
| RN3 | 10 kΩ | Pull-up em 3,3 V para os sensores SI01 a SI03, CF09 e CF10 |

A função de RN3 é clara: garantir nível alto definido nas entradas quando o sensor está em repouso.

A função de RN1 e RN2 é definir o nível das entradas dos L293D. Isso faz sentido porque a saída do
PCF8574 é quase bidirecional: ela puxa firmemente para o nível baixo, mas para o nível alto conta
apenas com uma fonte de corrente interna fraca, de cerca de 100 microampères. Um pull-up externo
firma o nível alto e melhora o tempo de subida.

Vale notar que os sensores CF01 a CF08 não têm rede de pull-up externa no esquemático. Eles dependem
do pull-up interno da Raspberry Pi, que o código de fato habilita com `GPIO.PUD_UP`. Funciona, mas
o pull-up interno é da ordem de 50 kΩ, bem mais fraco que os 10 kΩ usados nos outros sensores, o que
os torna mais suscetíveis a ruído captado no cabeamento. Ver [P6](09-pendencias-e-roadmap.md).

## 2.9 Recortes do esquemático

Para facilitar a leitura, os blocos principais estão ampliados abaixo.

### Bloco do controlador e sensores

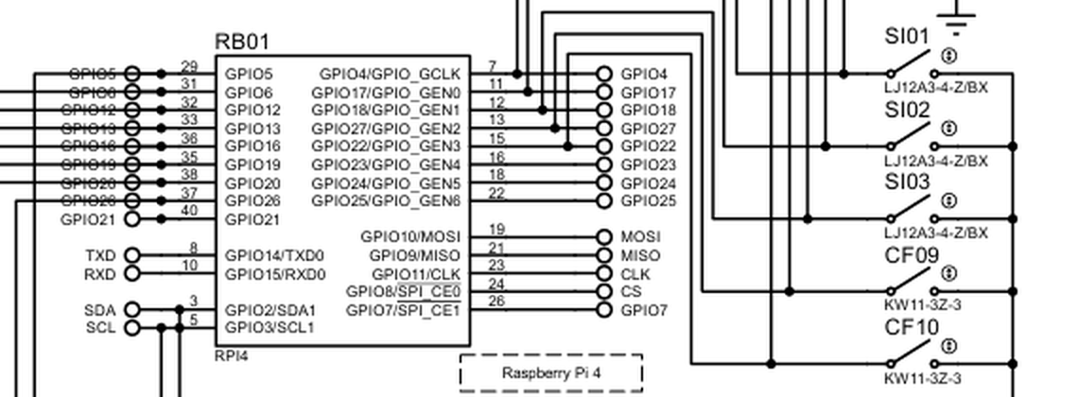
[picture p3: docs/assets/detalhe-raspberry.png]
Detalhe da Raspberry Pi


Aqui se vê a Raspberry Pi 4 (RB01) com os números de pino físico ao lado de cada GPIO, e à direita
os três sensores indutivos SI01 a SI03 e as chaves CF09 e CF10.

### Bloco dos expansores de I/O

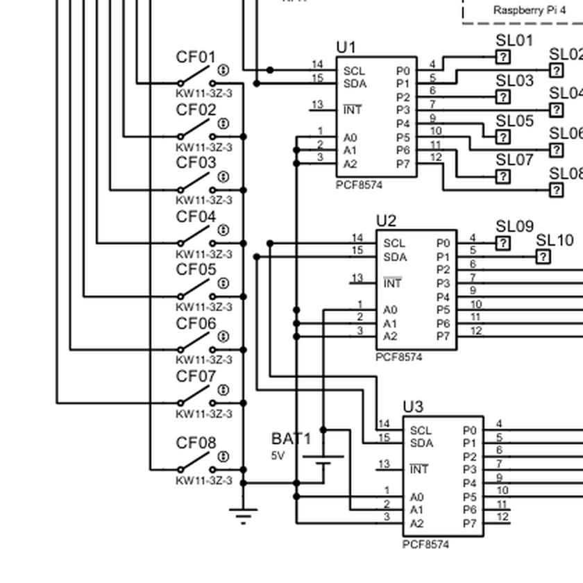
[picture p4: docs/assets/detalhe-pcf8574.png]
Detalhe dos PCF8574


À esquerda as oito chaves de fim de curso CF01 a CF08, cada uma com um terminal ao barramento de
terra e o outro indo para um GPIO. À direita os três PCF8574, com SCL no pino 14, SDA no pino 15,
INT no pino 13 e os pinos de endereço A0, A1 e A2 embaixo. As saídas de U1 vão para SL01 a SL08, e
as duas primeiras de U2 para SL09 e SL10.

### Bloco de potência

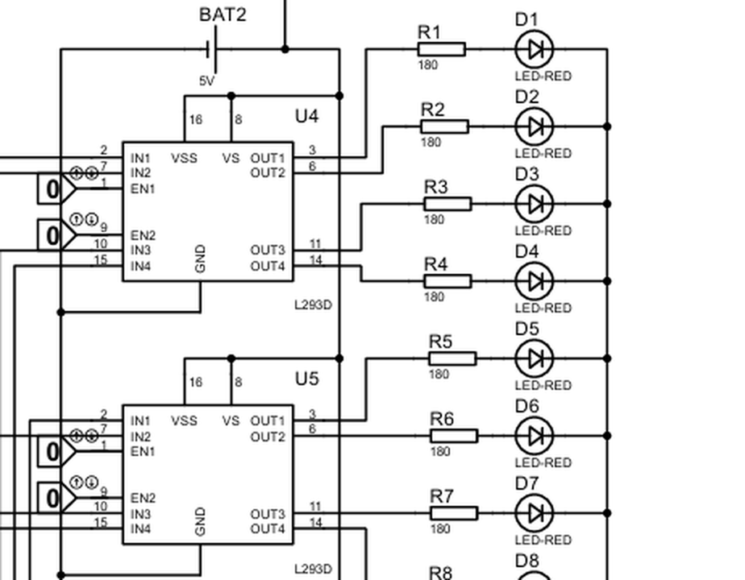
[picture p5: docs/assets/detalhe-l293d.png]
Detalhe dos L293D


Cada L293D recebe 5 V de BAT2 nos pinos 16 (VSS) e 8 (VS), tem GND aterrado, recebe comando em IN1,
IN2, IN3 e IN4, e entrega em OUT1, OUT2, OUT3 e OUT4. Cada saída vai a um resistor de 180 ohms e a
um LED.

Note os blocos com o valor `0` ligados a EN1 e EN2: são atuadores de estado lógico do Proteus,
usados para alternar o sinal manualmente durante a simulação. No hardware real esses pinos de
habilitação precisam de uma origem definida, seja uma saída de expansor ou uma amarração fixa em
nível alto. Ver [P3](09-pendencias-e-roadmap.md).

---

Anterior: [01. Visão geral](01-visao-geral.md) · Próximo: [03. Componentes](03-componentes.md)

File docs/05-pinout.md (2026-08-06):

[Voltar ao índice](../README.md)

# 05. Pinagem e mapa de I/O

Este documento reúne todas as ligações do projeto em forma de tabela. Onde uma informação não pode
ser determinada com certeza a partir do esquemático, isso está indicado de forma explícita em vez de
ser preenchido por suposição.

## 5.1 Raspberry Pi, entradas digitais

O código configura 16 GPIOs como entrada com pull-up interno, na lista definida em
`src/components/Raspberry.py`:

```python
self.entradas = [
    4, 17, 27, 22, 5, 6, 13, 19,
    26, 23, 24, 25, 12, 16, 20, 21
]
```

Esses 16 GPIOs correspondem exatamente aos que aparecem ligados no esquemático, o que confirma que
código e hardware estão de acordo neste ponto. A tabela abaixo cruza numeração BCM, pino físico do
conector de 40 vias e a posição no esquemático.

| GPIO (BCM) | Pino físico | Bloco no esquemático | Observação |
|---|---|---|---|
| GPIO4 | 7 | Superior (sensores) | |
| GPIO5 | 29 | Esquerdo (fim de curso) | |
| GPIO6 | 31 | Esquerdo (fim de curso) | |
| GPIO12 | 32 | Esquerdo (fim de curso) | |
| GPIO13 | 33 | Esquerdo (fim de curso) | |
| GPIO16 | 36 | Esquerdo (fim de curso) | |
| GPIO17 | 11 | Superior (sensores) | |
| GPIO19 | 35 | Esquerdo (fim de curso) | |
| GPIO20 | 38 | Esquerdo (fim de curso) | |
| GPIO21 | 40 | Esquerdo (fim de curso) | |
| GPIO22 | 15 | Superior (sensores) | |
| GPIO23 | 16 | Superior (sensores) | |
| GPIO24 | 18 | Superior (sensores) | |
| GPIO25 | 22 | Superior (sensores) | |
| GPIO26 | 37 | Esquerdo (fim de curso) | |
| GPIO27 | 13 | Superior (sensores) | |

São 16 entradas para 13 sensores, o que deixa 3 GPIOs de reserva.

O esquemático mostra também um GPIO18 desenhado no símbolo da Raspberry Pi, mas ele não aparece na
lista do código e não está ligado a sensor algum. Não faz parte do banco de entradas.

## 5.2 Mapeamento sensor para GPIO

Este é o ponto em que a documentação da etapa anterior não permite conclusão. O esquemático liga os
sensores aos GPIOs por fios que se cruzam ao longo do desenho, sem rótulos de rede (net labels), e a
imagem exportada não permite rastrear com segurança qual fio chega a qual pino.

O que se sabe com certeza:

- Os 13 sensores estão distribuídos entre os 16 GPIOs da tabela anterior.
- CF01 a CF08 estão no bloco esquerdo, cujos fios vão para GPIO5, GPIO6, GPIO12, GPIO13, GPIO16,
  GPIO19, GPIO20, GPIO21 e GPIO26.
- SI01 a SI03, CF09 e CF10 estão no bloco superior, cujos fios vão para GPIO4, GPIO17, GPIO22,
  GPIO23, GPIO24, GPIO25 e GPIO27.

O que precisa ser confirmado abrindo o projeto no Proteus e inspecionando cada nó, ou medindo com
multímetro na montagem física:

| Sensor | Tipo | GPIO | Função no jogo |
|---|---|---|---|
| SI01 | Indutivo | a confirmar | a definir |
| SI02 | Indutivo | a confirmar | a definir |
| SI03 | Indutivo | a confirmar | a definir |
| CF01 | Fim de curso | a confirmar | a definir |
| CF02 | Fim de curso | a confirmar | a definir |
| CF03 | Fim de curso | a confirmar | a definir |
| CF04 | Fim de curso | a confirmar | a definir |
| CF05 | Fim de curso | a confirmar | a definir |
| CF06 | Fim de curso | a confirmar | a definir |
| CF07 | Fim de curso | a confirmar | a definir |
| CF08 | Fim de curso | a confirmar | a definir |
| CF09 | Fim de curso | a confirmar | a definir |
| CF10 | Fim de curso | a confirmar | a definir |

Preencher esta tabela é uma das primeiras tarefas de quem continuar o projeto, e o procedimento
está descrito em [09. Pendências, item P7](09-pendencias-e-roadmap.md).

## 5.3 Raspberry Pi, barramento I²C

| Sinal | GPIO (BCM) | Pino físico | Destino |
|---|---|---|---|
| SDA | GPIO2 | 3 | Pino 15 de U1, U2 e U3 |
| SCL | GPIO3 | 5 | Pino 14 de U1, U2 e U3 |

O barramento usado é o `I2C1`, que precisa estar habilitado no sistema. Ver
[06. Software](06-software.md) para o procedimento.

## 5.4 Raspberry Pi, pinos desenhados mas não usados

O símbolo do Proteus expõe outros pinos que aparecem no desenho sem função atribuída no projeto:

| Sinal | GPIO | Pino físico | Situação |
|---|---|---|---|
| TXD | GPIO14 | 8 | Desenhado, sem uso |
| RXD | GPIO15 | 10 | Desenhado, sem uso |
| MOSI | GPIO10 | 19 | Desenhado, sem uso |
| MISO | GPIO9 | 21 | Desenhado, sem uso |
| CLK | GPIO11 | 23 | Desenhado, sem uso |
| CS | GPIO8 | 24 | Desenhado, sem uso |
| SPI_CE1 | GPIO7 | 26 | Desenhado, sem uso |

Esses pinos ficam disponíveis para expansões. A UART (TXD e RXD) é justamente o caminho natural para
a comunicação com o ESP32 prevista no roadmap, e o SPI ficaria livre para um display de placar.

## 5.5 PCF8574, endereços

### Situação no esquemático

| CI | A2 | A1 | A0 | Endereço resultante |
|---|---|---|---|---|
| U1 | GND | GND | GND | `0x20` |
| U2 | GND | GND | GND | `0x20` |
| U3 | GND | GND | GND | `0x20` |

Os três pinos de seleção dos três CIs estão ligados no mesmo nó, e esse nó vai ao terra. O resultado
é que os três respondem no mesmo endereço, o que impossibilita endereçá-los individualmente.

### Situação no código

O arquivo `src/main.py` instancia um único módulo:

```python
pcf = rasp.adiciona_modulo(0x27)   # endereço 0x27
```

O endereço `0x27` corresponde a A0, A1 e A2 todos em nível alto, o oposto do que o esquemático
desenha. Já o código de teste do relatório e o firmware da simulação usam `0x20`.

Ou seja, há três fontes divergindo entre si. A correção proposta está em
[09. Pendências, item P1](09-pendencias-e-roadmap.md), e a atribuição recomendada é:

| CI | A2 | A1 | A0 | Endereço | Função |
|---|---|---|---|---|---|
| U1 | GND | GND | GND | `0x20` | Solenoides SL01 a SL08 |
| U2 | GND | GND | VDD | `0x21` | Solenoides SL09 e SL10, e comando de driver |
| U3 | GND | VDD | GND | `0x22` | Comando de driver |

## 5.6 PCF8574, mapa de saídas

### U1, solenoides

| Pino do CI | Bit | Saída | Destino |
|---|---|---|---|
| 4 | P0 | SL01 | Solenoide |
| 5 | P1 | SL02 | Solenoide |
| 6 | P2 | SL03 | Solenoide |
| 7 | P3 | SL04 | Solenoide |
| 9 | P4 | SL05 | Solenoide |
| 10 | P5 | SL06 | Solenoide |
| 11 | P6 | SL07 | Solenoide |
| 12 | P7 | SL08 | Solenoide |

### U2, solenoides e comando de driver

| Pino do CI | Bit | Destino |
|---|---|---|
| 4 | P0 | SL09, solenoide |
| 5 | P1 | SL10, solenoide |
| 6 | P2 | Entrada de L293D, via RN1 ou RN2 |
| 7 | P3 | Entrada de L293D, via RN1 ou RN2 |
| 9 | P4 | Entrada de L293D, via RN1 ou RN2 |
| 10 | P5 | Entrada de L293D, via RN1 ou RN2 |
| 11 | P6 | Entrada de L293D, via RN1 ou RN2 |
| 12 | P7 | Entrada de L293D, via RN1 ou RN2 |

### U3, comando de driver

| Pino do CI | Bit | Destino |
|---|---|---|
| 4 | P0 | Entrada de L293D, via RN1 ou RN2 |
| 5 | P1 | Entrada de L293D, via RN1 ou RN2 |
| 6 | P2 | Entrada de L293D, via RN1 ou RN2 |
| 7 | P3 | Entrada de L293D, via RN1 ou RN2 |
| 9 | P4 | Entrada de L293D, via RN1 ou RN2 |
| 10 | P5 | Entrada de L293D, via RN1 ou RN2 |
| 11 | P6 | Entrada de L293D, via RN1 ou RN2 |
| 12 | P7 | Entrada de L293D, via RN1 ou RN2 |

Somando P2 a P7 de U2 com P0 a P7 de U3, há 14 linhas de comando disponíveis para as 12 entradas dos
três L293D. Assim como no caso dos sensores, o esquemático não permite determinar qual linha chega a
qual entrada, porque os fios se cruzam sem rótulo de rede. Essa correspondência precisa ser levantada
no Proteus.

## 5.7 L293D, mapa de ligações

Todos os três CIs seguem o mesmo padrão de alimentação:

| Pino | Nome | Ligação |
|---|---|---|
| 16 | VSS | 5 V, de BAT2 |
| 8 | VS | 5 V, de BAT2 |
| 4, 5, 12, 13 | GND | Terra |

E o mesmo padrão de entradas e saídas:

| Pino | Nome | Origem ou destino |
|---|---|---|
| 1 | EN1 | Atuador de simulação no esquemático, sem origem definida no hardware |
| 9 | EN2 | Atuador de simulação no esquemático, sem origem definida no hardware |
| 2 | IN1 | Saída de PCF8574 |
| 7 | IN2 | Saída de PCF8574 |
| 10 | IN3 | Saída de PCF8574 |
| 15 | IN4 | Saída de PCF8574 |
| 3 | OUT1 | Resistor e LED |
| 6 | OUT2 | Resistor e LED |
| 11 | OUT3 | Resistor e LED |
| 14 | OUT4 | Resistor e LED |

### Correspondência entre saídas e LEDs

| CI | OUT1 | OUT2 | OUT3 | OUT4 |
|---|---|---|---|---|
| U4 | R1 e D1 | R2 e D2 | R3 e D3 | R4 e D4 |
| U5 | R5 e D5 | R6 e D6 | R7 e D7 | R8 e D8 |
| U6 | R9 e D9 | R10 e D10 | R11 e D11 | R12 e D12 |

Todos os resistores R1 a R12 são de 180 ohms, e todos os LEDs D1 a D12 são vermelhos de 5 mm.

Sobre os pinos de habilitação: no esquemático eles estão ligados a atuadores de estado lógico do
Proteus, que servem para alternar o sinal manualmente durante a simulação. No hardware real esses
pinos precisam de uma origem definida. Ver [P3](09-pendencias-e-roadmap.md).

## 5.8 Alimentação

| Fonte | Tensão | Cargas |
|---|---|---|
| BAT1 | 5 V | VDD dos três PCF8574 |
| BAT2 | 5 V | VSS e VS dos três L293D |
| BAT3 | 3,3 V | Comum da rede RN3 |

Todas as referências de terra são comuns, conforme o barramento de terra do esquemático.

Não há fonte prevista para as solenoides, que é uma lacuna do projeto. Ver
[P2](09-pendencias-e-roadmap.md).

## 5.9 Redes resistivas

| Rede | Valor | Elementos | Comum ligado a | Função |
|---|---|---|---|---|
| RN1 | 10 kΩ | 8 | Barramento de saída dos PCF | Pull-up nas linhas de comando dos drivers |
| RN2 | 10 kΩ | 8 | Barramento de saída dos PCF | Pull-up nas linhas de comando dos drivers |
| RN3 | 10 kΩ | 8 | BAT3, 3,3 V | Pull-up nas entradas de sensor |

## 5.10 Referência rápida do conector da Raspberry Pi

Para consulta durante a montagem, com os pinos usados neste projeto destacados na coluna de função.

| Pino | Sinal | Função no projeto | | Pino | Sinal | Função no projeto |
|---|---|---|---|---|---|---|
| 1 | 3V3 | | | 2 | 5V | |
| 3 | GPIO2 | **SDA, I²C** | | 4 | 5V | |
| 5 | GPIO3 | **SCL, I²C** | | 6 | GND | Terra |
| 7 | GPIO4 | **Entrada de sensor** | | 8 | GPIO14 | Livre (UART TX) |
| 9 | GND | Terra | | 10 | GPIO15 | Livre (UART RX) |
| 11 | GPIO17 | **Entrada de sensor** | | 12 | GPIO18 | Livre |
| 13 | GPIO27 | **Entrada de sensor** | | 14 | GND | Terra |
| 15 | GPIO22 | **Entrada de sensor** | | 16 | GPIO23 | **Entrada de sensor** |
| 17 | 3V3 | | | 18 | GPIO24 | **Entrada de sensor** |
| 19 | GPIO10 | Livre (SPI MOSI) | | 20 | GND | Terra |
| 21 | GPIO9 | Livre (SPI MISO) | | 22 | GPIO25 | **Entrada de sensor** |
| 23 | GPIO11 | Livre (SPI CLK) | | 24 | GPIO8 | Livre (SPI CE0) |
| 25 | GND | Terra | | 26 | GPIO7 | Livre (SPI CE1) |
| 27 | GPIO0 | Reservado (EEPROM) | | 28 | GPIO1 | Reservado (EEPROM) |
| 29 | GPIO5 | **Entrada de sensor** | | 30 | GND | Terra |
| 31 | GPIO6 | **Entrada de sensor** | | 32 | GPIO12 | **Entrada de sensor** |
| 33 | GPIO13 | **Entrada de sensor** | | 34 | GND | Terra |
| 35 | GPIO19 | **Entrada de sensor** | | 36 | GPIO16 | **Entrada de sensor** |
| 37 | GPIO26 | **Entrada de sensor** | | 38 | GPIO20 | **Entrada de sensor** |
| 39 | GND | Terra | | 40 | GPIO21 | **Entrada de sensor** |

---

Anterior: [04. Circuitos integrados](04-circuitos-integrados.md) ·
Próximo: [06. Software](06-software.md)

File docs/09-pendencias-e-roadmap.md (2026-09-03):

[Voltar ao índice](../README.md)

# 09. Pendências e roadmap

Este documento lista o que está errado, o que está faltando e em que ordem atacar. Os itens vêm de
três fontes: problemas relatados pela equipe anterior no relatório final, divergências encontradas ao
comparar o esquemático com o código, e lacunas de projeto identificadas na revisão.

## 9.1 Resumo por prioridade

| Item | Assunto | Gravidade |
|---|---|---|
| [P1](#p1-conflito-de-endereço-i2c-nos-três-pcf8574) | Os três PCF8574 no mesmo endereço I²C | Crítico |
| [P2](#p2-acionamento-das-solenoides-não-projetado) | Acionamento das solenoides não projetado | Crítico |
| [P3](#p3-pinos-de-habilitação-dos-l293d-sem-origem) | Habilitação dos L293D sem origem definida | Alto |
| [P4](#p4-compatibilidade-de-níveis-entre-33-v-e-5-v) | Compatibilidade de níveis entre 3,3 V e 5 V | Alto |
| [P5](#p5-pull-up-do-barramento-i2c-não-verificado) | Pull-up do I²C não verificado para cabo longo | Médio |
| [P6](#p6-pull-up-fraco-nos-sensores-cf01-a-cf08) | Pull-up interno fraco em CF01 a CF08 | Médio |
| [P7](#p7-mapeamento-de-sensores-não-documentado) | Mapeamento de sensores não documentado | Médio |
| [P8](#p8-licença-declarada-mas-ausente) | Licença declarada mas sem arquivo | Médio |
| [P9](#p9-repique-de-contato-sem-tratamento) | Repique de contato sem tratamento | Médio |
| [P10](#p10-corrente-dos-leds-abaixo-do-previsto) | Corrente dos LEDs abaixo do previsto | Baixo |
| [P11](#p11-arquivos-3d-originais-não-recuperados) | Arquivos 3D originais não recuperados | Médio |
| [P12](#p12-problemas-menores-de-código) | Problemas menores de código | Baixo |

## P1. Conflito de endereço I2C nos três PCF8574

**Gravidade: crítico.**

### O problema

No esquemático, os pinos A0, A1 e A2 dos três PCF8574 estão ligados no mesmo nó, e esse nó vai ao
terra. Como o endereço do PCF8574 é definido justamente por esses três pinos, os três CIs respondem
no endereço `0x20` simultaneamente.

Isso é um conflito de barramento. Quando o mestre escreve em `0x20`, os três expansores recebem o
mesmo byte e acionam suas saídas juntos. Não há como comandar um sem comandar os outros. Numa
leitura, os três tentam responder ao mesmo tempo e o resultado é indefinido.

### Por que isso importa tanto

O relatório da etapa anterior descreve "falhas intermitentes no reconhecimento de sensores",
"dificuldades na comunicação via barramento I²C" e "inconsistências no funcionamento de módulos
externos", que exigiram "reconfiguração de endereços" e "substituição de componentes". Esses sintomas
são exatamente o que um conflito de endereço produz. É bem provável que este seja o problema raiz por
trás de boa parte do tempo perdido em bancada.

### Como confirmar

Na Raspberry Pi, com o hardware montado:

```bash
i2cdetect -y 1
```

Se aparecer apenas `20` com os três expansores ligados, o conflito está confirmado. Se os três
estivessem corretamente endereçados, apareceriam três endereços distintos.

### A correção

Ligar os pinos de seleção de forma diferente em cada CI. Nível baixo é ligar ao terra, nível alto é
ligar ao VDD do CI.

| CI | A2 | A1 | A0 | Endereço | Função |
|---|---|---|---|---|---|
| U1 | GND | GND | GND | `0x20` | Solenoides SL01 a SL08 |
| U2 | GND | GND | VDD | `0x21` | Solenoides SL09 e SL10, comando de driver |
| U3 | GND | VDD | GND | `0x22` | Comando de driver |

Depois de corrigir o esquemático, o código precisa instanciar os três:

```python
rasp = Raspberry()
pcf_sol1 = rasp.adiciona_modulo(0x20)
pcf_sol2 = rasp.adiciona_modulo(0x21)
pcf_leds = rasp.adiciona_modulo(0x22)
```

### Pendência associada no código

O `src/main.py` usa hoje o endereço `0x27`, que corresponde a A0, A1 e A2 todos em nível alto. Não
corresponde nem ao esquemático nem ao firmware da simulação, que usam `0x20`. As três fontes precisam
ficar coerentes.

## P2. Acionamento das solenoides não projetado

**Gravidade: crítico.**

### O problema

As dez solenoides SL01 a SL10 estão ligadas diretamente aos pinos dos PCF8574, e no esquemático
aparecem como símbolos sem modelo atribuído. Não existe estágio de potência entre o expansor e a
carga.

Um pino de PCF8574 drena no máximo 25 mA. Uma solenoide de flipper de pinball puxa vários ampères no
pulso. Ligar uma na outra destrói o expansor imediatamente.

Há também uma divergência entre documentos: o relatório afirma que os L293D serviriam de driver tanto
para os LEDs quanto para as solenoides, mas o esquemático só implementa o caminho dos LEDs.

### Por que o L293D não resolve

Mesmo que as solenoides fossem ligadas aos L293D, não funcionaria. O L293D entrega 600 mA contínuos e
1,2 A de pico por canal, uma ordem de magnitude abaixo do necessário. E a tensão máxima de 36 V
limita as opções de fonte.

### O que precisa ser projetado

**Estágio de potência.** Um MOSFET de canal N por solenoide, com resistência de condução baixa,
comandado pelo pino do PCF8574 através de um resistor de gate. O MOSFET precisa ser dimensionado para
a corrente de pico com folga. Uma alternativa é usar módulos de driver de alta corrente prontos, o
que reduz o trabalho de projeto de placa.

**Diodo de recuperação.** Obrigatório, em antiparalelo com cada bobina. Ao desligar a solenoide, o
colapso do campo magnético gera um pico de tensão invertida que pode chegar a centenas de volts e
destrói o MOSFET. O diodo dá um caminho para essa corrente. Deve ser de recuperação rápida e
suportar a corrente da bobina.

**Fonte dedicada.** Solenoides de pinball tipicamente operam entre 24 V e 48 V. Essa fonte precisa
ser separada da fonte lógica, e os terras precisam ser unidos em um único ponto para evitar que a
corrente de pulso circule pelo terra da lógica.

**Limite de tempo de acionamento.** Este é o ponto mais importante. Uma solenoide de pinball é
projetada para pulsos de 30 ms a 50 ms. Energizada continuamente, a bobina superaquece e queima em
segundos. O software precisa garantir o desligamento, e é fortemente recomendável ter também uma
proteção em hardware que corte o acionamento independentemente do software, porque uma travada do
programa com a solenoide ligada significa dano físico.

**Desacoplamento.** Capacitores de desacoplamento próximos aos drivers, para absorver o transiente de
corrente do pulso e evitar que a queda de tensão momentânea reinicie a lógica.

### Cuidado com a fonte de 24 V ou 48 V perto da lógica

Com uma fonte dessa tensão no mesmo gabinete, um erro de fiação pode levar 24 V a um GPIO de 3,3 V.
Vale separar fisicamente o cabeamento de potência do de sinal, usar conectores diferentes para os dois
domínios, e conferir com multímetro antes de energizar a Raspberry Pi pela primeira vez.

## P3. Pinos de habilitação dos L293D sem origem

**Gravidade: alto.**

No esquemático, os pinos EN1 e EN2 dos três L293D estão ligados a atuadores de estado lógico do
Proteus, que são componentes de simulação usados para alternar um sinal manualmente clicando com o
mouse. Eles não existem no hardware real.

Sem uma origem definida, esses pinos ficam flutuando na montagem física, e o comportamento das saídas
é imprevisível.

Há duas soluções, e a escolha depende do que se quer.

A mais simples é amarrar EN1 e EN2 ao VCC de 5 V através de um resistor, deixando os canais sempre
habilitados e controlando cada LED apenas pela entrada IN correspondente. Resolve o problema com um
resistor.

A mais flexível é ligar EN1 e EN2 a saídas de PCF8574, o que permite apagar pares de canais de uma
vez, útil para efeitos de luz sincronizados e para um desligamento geral rápido. Custa seis pinos de
expansor, e é preciso verificar se há saídas sobrando.

## P4. Compatibilidade de níveis entre 3,3 V e 5 V

**Gravidade: alto.**

Os GPIOs da Raspberry Pi trabalham em 3,3 V e não toleram 5 V. Aplicar 5 V numa entrada danifica o
SoC de forma permanente. No esquemático há dois pontos que merecem verificação.

**Barramento I²C.** Os PCF8574 estão alimentados em 5 V, por BAT1. Num barramento I²C, tanto SDA
quanto SCL são bidirecionais e em dreno aberto, e o nível alto é definido por quem tem o pull-up. Se
houver um pull-up para 5 V em algum ponto do barramento, esses 5 V chegam ao GPIO da Pi.

Há duas saídas. A mais simples é alimentar os PCF8574 em 3,3 V em vez de 5 V, o que é permitido pelo
CI, que aceita de 2,5 V a 6 V. Isso elimina o problema na origem e é a recomendação. A alternativa é
manter os expansores em 5 V e usar um conversor de nível bidirecional, tipo módulo com MOSFETs BSS138,
entre a Pi e o barramento.

Alimentar em 3,3 V tem uma consequência a considerar: as saídas do expansor passam a fornecer nível
alto de 3,3 V, o que ainda é suficiente para as entradas do L293D, cujo limiar de nível alto é de
cerca de 2,3 V.

**Sensores indutivos.** O LJ12A3-4-Z/BX é especificado para alimentação de 6 V a 36 V, tipicamente
12 V ou 24 V. Se a saída do sensor tiver qualquer caminho interno para a alimentação, esses 24 V
chegam ao GPIO.

O esquemático adota a topologia correta, com a rede RN3 puxando para 3,3 V e o sensor apenas
drenando para o terra. Para que funcione, a saída precisa ser genuinamente coletor aberto. Antes de
ligar na Pi, vale medir a tensão na saída do sensor alimentado, com a linha em aberto e com um
pull-up para 3,3 V, confirmando que ela nunca passa de 3,3 V. Se passar, é necessário um divisor
resistivo ou um optoacoplador.

## P5. Pull-up do barramento I2C não verificado

**Gravidade: médio.**

O esquemático não mostra resistores de pull-up externos em SDA e SCL. A Raspberry Pi tem pull-ups
internos de cerca de 1,8 kΩ nesses dois pinos, que costumam bastar para trechos curtos.

Numa mesa de pinball, porém, o cabeamento é longo e passa perto de solenoides. Cabo longo significa
capacitância parasita maior, o que arredonda as bordas do sinal, e proximidade com bobinas significa
ruído injetado. Se aparecerem erros esporádicos de comunicação, este é um dos suspeitos.

O procedimento recomendado é manter o cabeamento do I²C o mais curto possível, usar par trançado ou
cabo blindado com a malha ao terra em um ponto só, roteá-lo afastado do cabeamento de potência das
solenoides, e verificar o formato das bordas de SCL com osciloscópio se houver instabilidade. Se as
bordas estiverem lentas, acrescentar pull-ups externos de 2,2 kΩ a 4,7 kΩ, lembrando que eles ficam
em paralelo com os internos.

## P6. Pull-up fraco nos sensores CF01 a CF08

**Gravidade: médio.**

As chaves CF01 a CF08 não têm rede de pull-up externa no esquemático. Elas dependem do pull-up
interno da Raspberry Pi, que o código habilita corretamente com `GPIO.PUD_UP`.

O pull-up interno é da ordem de 50 kΩ, bem mais fraco que os 10 kΩ da rede RN3 usada nos outros
sensores. Um pull-up fraco em um fio longo é mais suscetível a ruído captado por acoplamento
capacitivo, e o sintoma é acionamento fantasma: o software registra um alvo atingido sem que a bola
tenha passado.

Como CF01 a CF08 são provavelmente os alvos e os botões dos flippers, ou seja, o que mais importa
para a jogabilidade, vale padronizar. A recomendação é acrescentar uma rede resistiva de 10 kΩ para
3,3 V nessas oito linhas, igual à RN3, e opcionalmente um capacitor de 100 nF de cada linha para o
terra, formando um filtro RC que já ajuda no repique tratado em [P9](#p9-repique-de-contato-sem-tratamento).

## P7. Mapeamento de sensores não documentado

**Gravidade: médio.**

O esquemático liga os 13 sensores aos GPIOs por fios que se cruzam sem rótulos de rede, e a imagem
exportada não permite determinar com segurança qual sensor está em qual GPIO. Também não há indicação
de qual sensor cumpre qual papel no jogo.

Sem essa informação, não é possível escrever a lógica do jogo, porque o software não sabe se o GPIO5
é o botão do flipper esquerdo ou um alvo do canto superior.

Existem dois caminhos para resolver, e o ideal é fazer os dois.

O primeiro é abrir o projeto no Proteus e inspecionar cada nó, anotando a correspondência. É o
caminho mais rápido e independe do hardware estar montado.

O segundo é levantar na bancada, com o hardware ligado, usando o programa de diagnóstico proposto em
[06. Software, seção 6.4](06-software.md#64-o-main-atual). Ele imprime qual GPIO mudou de estado, e
basta acionar um sensor por vez e anotar. Esse método tem a vantagem de refletir a fiação real, que
pode divergir do esquemático.

O resultado deve preencher a tabela da
[seção 5.2](05-pinout.md#52-mapeamento-sensor-para-gpio) e ser codificado no `config/mapa_io.py`
sugerido em [06. Software, seção 6.7](06-software.md#67-estrutura-de-código-sugerida).

## P8. Licença declarada mas ausente

**Gravidade: médio.**

O README do repositório anterior afirma que o projeto está licenciado sob a MIT License e remete a um
arquivo `LICENSE`, mas esse arquivo não existe no repositório.

Juridicamente, código publicado sem licença permanece sob direito autoral integral dos autores, o que
significa que ninguém tem permissão explícita para usar, modificar ou redistribuir, apesar do que o
README diz.

Como o trabalho é acadêmico e a intenção declarada é clara, a resolução é simples: pedir aos autores
originais, Daniel Cardoso Fernandes e Roberto da Silva Espindola, que adicionem o arquivo `LICENSE`
com o texto da MIT ao repositório deles. Enquanto isso não acontecer, este repositório não deve
declarar licença própria sobre material de terceiros.

## P9. Repique de contato sem tratamento

**Gravidade: médio.**

Todo contato mecânico apresenta repique: nos primeiros milissegundos após o fechamento, o contato
abre e fecha várias vezes antes de estabilizar. Nas dez chaves KW11-3Z-3 do projeto isso vai
acontecer.

Sem tratamento, um único toque do jogador no botão do flipper é contado como vários acionamentos. A
pontuação fica errada e a solenoide recebe uma sequência de pulsos em vez de um.

A solução em software é direta, usando o parâmetro `bouncetime` da `RPi.GPIO`:

```python
GPIO.add_event_detect(pino, GPIO.FALLING,
                      callback=trata_sensor,
                      bouncetime=50)   # ignora novas transições por 50 ms
```

Vale notar que essa abordagem também resolve o problema do laço de varredura sem pausa apontado em
[06. Software](06-software.md), porque troca varredura por interrupção.

Um cuidado ao escolher o valor: para o botão do flipper, uma janela grande demais impede o jogador de
acionar em sequência rápida. Entre 20 ms e 50 ms é um ponto de partida razoável, a ajustar em teste.

A solução em hardware, complementar, é um filtro RC de 10 kΩ e 100 nF em cada linha, que dá uma
constante de tempo de 1 ms e já suaviza a maior parte do repique antes de chegar ao GPIO.

## P10. Corrente dos LEDs abaixo do previsto

**Gravidade: baixo.**

Os resistores R1 a R12 são de 180 ohms, valor coerente com um cálculo que supõe 5 V na saída do
driver:

```
R = (5 V - 2 V) / 20 mA = 150 Ω, arredondado para 180 Ω
```

O L293D, porém, perde cerca de 1,4 V internamente no transistor superior, então a tensão que chega ao
resistor é de aproximadamente 3,6 V:

```
I = (3,6 V - 2 V) / 180 Ω ≈ 8,9 mA
```

Os LEDs vão acender com menos da metade da corrente pretendida. Continuam visíveis, mas mais fracos do
que o projeto previa, o que numa mesa de pinball com iluminação ambiente pode ficar insuficiente.

Se o brilho não bastar na montagem, trocar para 82 ohms devolve cerca de 19,5 mA. Vale medir a tensão
real na saída do L293D antes de decidir o valor, porque a queda varia com a corrente.

Como observação de projeto, e não como erro: usar um L293D para acender quatro LEDs é desperdício de
recurso. Um ULN2803, com oito canais Darlington no mesmo tamanho de encapsulamento, cobriria os doze
LEDs com dois CIs em vez de três, com queda de tensão menor e custo mais baixo.

## P11. Arquivos 3D originais não recuperados

**Gravidade: médio.**

O relatório descreve em detalhe as peças mecânicas modeladas e impressas e cita os modelos de
referência usados, mas os arquivos que deram origem às peças da etapa anterior não estão no
repositório. Há um novo modelo editável do flipper em `mecanica/modelos-3d/`, porém ele ainda precisa
ser validado no protótipo físico e não substitui os modelos históricos das demais peças.

Se uma peça quebrar, e o relatório registra que peças quebraram durante os testes, será necessário
reprojetá-la do zero. O trabalho de modelagem, que consumiu boa parte do semestre, está preservado
apenas nas máquinas de quem o fez.

A ação é recuperar os arquivos com os autores originais e versioná-los em
`mecanica/modelos-3d/`, junto com um registro dos parâmetros de impressão que funcionaram: material,
altura de camada, preenchimento e orientação de cada peça.

## P12. Problemas menores de código

**Gravidade: baixo.**

Itens de limpeza no código atual, detalhados em [06. Software](06-software.md).

O `scan()` chama `carregar_entradas()` a cada varredura, reconfigurando os 16 GPIOs milhares de vezes
por segundo. A configuração pertence ao construtor.

O laço do `main.py` não tem pausa, consumindo 100% de um núcleo e produzindo saída ilegível.

O `import time` do `main.py` não é usado, e a variável `pcf` é criada e nunca utilizada.

O `_envia()` imprime a cada escrita, o que deve virar `logging` com nível de depuração.

O arquivo `requeriments.txt` está com o nome grafado errado e está vazio. Deveria ser
`requirements.txt` contendo `RPi.GPIO` e `smbus2`.

O `cleanup()` existe mas nunca é chamado, então os GPIOs ficam no último estado ao encerrar.

Falta um método de leitura na classe `Pcf8574`, e um método para escrever os oito bits de uma vez.

O arquivo `src/components/inductive_sensor.py` está vazio no repositório e deve ser implementado ou
removido.

## 9.2 Ordem de trabalho sugerida

A sequência abaixo respeita as dependências entre as tarefas: cada etapa depende do que vem antes.

```mermaid
flowchart TD
    A["<b>Etapa 1</b><br/>Levantar o mapeamento de I/O<br/>P7"] --> B["<b>Etapa 2</b><br/>Corrigir endereçamento I2C<br/>P1"]
    B --> C["<b>Etapa 3</b><br/>Resolver níveis e habilitação<br/>P3, P4, P6"]
    C --> D["<b>Etapa 4</b><br/>Validar em bancada<br/>LEDs e sensores"]
    D --> E["<b>Etapa 5</b><br/>Projetar acionamento<br/>de solenoide<br/>P2"]
    E --> F["<b>Etapa 6</b><br/>Testar uma solenoide<br/>isolada, com proteção"]
    F --> G["<b>Etapa 7</b><br/>Máquina de estados<br/>do jogo"]
    G --> H["<b>Etapa 8</b><br/>Montagem e ajuste<br/>mecânico"]
    H --> I["<b>Etapa 9</b><br/>Testes de campo<br/>e calibragem"]
```

O raciocínio por trás da ordem é o seguinte.

O mapeamento de I/O vem primeiro porque quase todo o resto depende de saber qual pino é o quê. É
também a tarefa mais barata e pode ser feita sem hardware montado, abrindo o Proteus.

O endereçamento I²C vem em segundo porque nada no lado das saídas funciona de forma controlável
enquanto os três expansores responderem no mesmo endereço.

Níveis e habilitação vêm antes de qualquer teste com hardware energizado, porque errar aqui queima a
Raspberry Pi.

A validação em bancada com LEDs e sensores é o primeiro marco de fato verificável: significa que o
caminho completo, da leitura de um sensor até o acendimento de um LED, está fechado. É um bom ponto de
parada para uma apresentação parcial.

O acionamento das solenoides vem depois, e não antes, porque é a parte que envolve risco de dano e de
projeto novo. Fazer isso com o resto já validado reduz a quantidade de variáveis quando algo der
errado.

Testar uma solenoide isolada antes de montar as dez é o que evita queimar dez bobinas por um erro de
tempo de pulso.

A lógica do jogo vem depois porque depende de todo o hardware responder de forma confiável. Escrever
máquina de estados contra hardware instável gera depuração no lugar errado.

## 9.3 Sobre a migração para ESP32 com RTOS

A conclusão da etapa anterior foi que a arquitetura ideal usa a Raspberry Pi para alto nível e um
ESP32 com RTOS para o tempo real. A recomendação é sólida, com uma ressalva de sequenciamento.

Não vale começar por ela. Migrar para uma arquitetura de dois processadores acrescenta um protocolo de
comunicação, uma segunda toolchain e uma nova classe de bugs de sincronização, tudo isso antes de
existir um pinball que funcione.

O caminho mais seguro é fechar primeiro uma versão jogável só com a Raspberry Pi, tratando os
sensores por interrupção e as solenoides com pulso protegido. Isso valida o hardware, a mecânica e as
regras do jogo com uma variável de menos.

Se, com isso funcionando, a resposta dos flippers se mostrar inconsistente na prática, aí a migração
do laço de tempo real para o ESP32 se justifica, e passa a ser uma otimização com problema conhecido
em vez de uma aposta arquitetural. O caminho de comunicação já está livre: GPIO14 e GPIO15, a UART,
não são usados por nada no projeto atual.

---

Anterior: [08. Simulação no Proteus](08-simulacao-proteus.md)

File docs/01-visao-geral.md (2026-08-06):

[Voltar ao índice](../README.md)

# 01. Visão geral

## 1.1 Objetivo

O projeto nasceu no contexto da Feira de Jogos do IFSC, Campus São José, um evento em que as turmas
de Projeto Integrador desenvolvem jogos físicos interativos. A proposta desta frente foi construir
uma máquina de pinball completa, do zero, usando apenas conhecimentos já adquiridos ao longo do
curso de Engenharia de Telecomunicações.

O pinball serve bem como projeto integrador porque exige, ao mesmo tempo, eletrônica digital
(sensores, atuadores, expansão de I/O, drivers de potência), sistemas embarcados (leitura de
sensores em tempo real, protocolos de comunicação), programação (máquina de estados do jogo,
pontuação, concorrência) e mecânica (estrutura, modelagem 3D, impressão aditiva, ajuste de
mecanismos móveis).

## 1.2 Escopo entregue pela etapa anterior

A equipe anterior, duas pessoas ao longo de um semestre, entregou quatro frentes.

O projeto mecânico inclui a modelagem 3D da mesa e dos obstáculos, com peças já impressas: bumpers,
flippers, injetor de bolas e repositor. Detalhes em [07. Mecânica](07-mecanica.md).

O projeto eletrônico é um esquemático completo feito no Proteus, com Raspberry Pi 4, três expansores
PCF8574, três drivers L293D, sensores e atuadores. Detalhes em
[02. Arquitetura de hardware](02-arquitetura-hardware.md).

A simulação validou a comunicação I²C entre a Raspberry Pi e o PCF8574 dentro do Proteus, antes da
montagem física. Detalhes em [08. Simulação no Proteus](08-simulacao-proteus.md).

Os drivers de software são duas classes Python, `Raspberry` e `Pcf8574`, que abstraem o acesso a
GPIO e I²C. Detalhes em [06. Software](06-software.md).

O que não foi entregue: a lógica do jogo, a integração final e a montagem completa da máquina.

## 1.3 Como um pinball funciona

Entender o fluxo do jogo é o que dá sentido a cada componente eletrônico do esquemático. O ciclo é
o seguinte.

```mermaid
flowchart TD
    Start([Ligar a máquina])
    Attract["Modo atração<br/>LEDs piscando, aguardando jogador"]
    WaitStart{"Jogador<br/>apertou START?"}
    Init["Inicializar partida<br/>pontuação = 0, bola = 1"]
    Launch["Injetor lança a bola<br/>na rampa de entrada"]
    Play["Bola em jogo<br/>flippers ativos"]
    Event{"Sensor<br/>acionado?"}
    Score["Somar pontos,<br/>acender LEDs,<br/>acionar bumper"]
    Drain{"Bola caiu<br/>no dreno?"}
    Count["bola = bola + 1"]
    More{"bola menor ou<br/>igual a 3?"}
    Over["Fim de jogo<br/>exibir pontuação"]

    Start --> Attract --> WaitStart
    WaitStart -- Não --> Attract
    WaitStart -- Sim --> Init --> Launch --> Play
    Play --> Event
    Event -- Sim --> Score --> Play
    Event -- Não --> Drain
    Play --> Drain
    Drain -- Não --> Play
    Drain -- Sim --> Count --> More
    More -- Sim --> Launch
    More -- Não --> Over --> Attract
```

Mapeando cada etapa para o hardware:

| Etapa do jogo | Componente responsável |
|---|---|
| Detectar que a bola passou por um ponto | Sensor indutivo `LJ12A3-4-Z/BX` |
| Detectar que a bola bateu num alvo | Fim de curso `KW11-3Z-3` |
| Ler o botão START e posições de mecanismos | Fim de curso `KW11-3Z-3` |
| Empurrar a bola (flipper, bumper, injetor) | Solenoide acionada via `PCF8574` |
| Iluminação cênica e feedback visual | LED vermelho acionado via `L293D` |
| Contar pontos e decidir o que acontece | Software na Raspberry Pi 4 |

## 1.4 Decisões de arquitetura e o porquê

**Raspberry Pi 4 como cérebro.** Roda Python direto, tem I²C nativo, facilita a depuração e abre
caminho para uma interface gráfica de placar mais adiante.

**Expansores PCF8574 no barramento I²C.** A Pi oferece cerca de 26 GPIOs úteis, e o pinball precisa
de mais de 40 pontos de I/O entre sensores, solenoides e luzes. Cada PCF8574 acrescenta 8 I/Os
usando apenas dois fios do barramento.

**Sensores ligados direto no GPIO, não via PCF8574.** A razão é latência. O flipper precisa
responder em milissegundos ao comando do jogador, e uma transação I²C acrescentaria atraso e jitter
no caminho crítico. Por isso os 13 sensores foram para GPIOs dedicados.

**Drivers L293D para as cargas.** O PCF8574 fornece corrente da ordem de poucos miliampères por
pino, insuficiente para acionar LEDs com brilho adequado e muito abaixo do necessário para
solenoides. O L293D resolve isso funcionando como estágio de potência.

**Migração planejada para RTOS em ESP32.** Python rodando sobre Linux não garante o determinismo
temporal que os flippers exigem. A conclusão da etapa anterior foi que a Pi deve cuidar da lógica
de alto nível e um microcontrolador com RTOS deve cuidar do tempo real. Ver
[09. Pendências e roadmap](09-pendencias-e-roadmap.md).

## 1.5 Glossário

| Termo | Significado |
|---|---|
| Flipper | O batedor acionado pelo jogador para rebater a bola |
| Bumper | Obstáculo circular que repele a bola ativamente e pontua |
| Dreno (drain) | Abertura no fundo da mesa por onde a bola é perdida |
| Injetor (ball launcher) | Mecanismo que coloca a bola em jogo |
| Modo atração (attract mode) | Estado de espera, com luzes e sons, para atrair jogadores |
| Solenoide | Atuador eletromagnético que puxa um núcleo metálico com força ao ser energizado |
| I²C | Barramento serial de dois fios, dados e clock, para comunicação entre CIs |
| GPIO | General Purpose Input/Output, pino digital genérico |
| Expansor de I/O | CI que acrescenta pinos digitais ao sistema através de um barramento serial |
| Pull-up | Resistor que mantém um sinal em nível alto quando nada o está forçando |
| RTOS | Real-Time Operating System, sistema operacional com prazos de resposta garantidos |
| Dreno de corrente (sink) | Saída que conduz corrente para o terra em vez de fornecê-la |

---

Próximo: [02. Arquitetura de hardware](02-arquitetura-hardware.md)

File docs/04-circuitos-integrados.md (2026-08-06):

[Voltar ao índice](../README.md)

# 04. Circuitos integrados

O projeto usa dois circuitos integrados, em três unidades cada. Este documento trata dos dois em
detalhe: pinagem, funcionamento, protocolo e limites elétricos. O papel de cada um no pinball está
em [03. Componentes](03-componentes.md).

## 4.1 PCF8574, expansor de I/O I²C

### Identificação

Fabricado por NXP e Texas Instruments, entre outros. Encapsulamento DIP-16 ou SO-16. O nome completo
é "Remote 8-bit I/O expander for I2C-bus". Existe uma variante PCF8574**A** que difere apenas na
faixa de endereços, o que importa quando se precisa de mais de oito expansores no mesmo barramento.

### Pinagem

| Pino | Nome | Direção | Descrição |
|---|---|---|---|
| 1 | A0 | Entrada | Bit 0 do endereço I²C |
| 2 | A1 | Entrada | Bit 1 do endereço I²C |
| 3 | A2 | Entrada | Bit 2 do endereço I²C |
| 4 | P0 | Bidirecional | I/O de dados, bit 0 |
| 5 | P1 | Bidirecional | I/O de dados, bit 1 |
| 6 | P2 | Bidirecional | I/O de dados, bit 2 |
| 7 | P3 | Bidirecional | I/O de dados, bit 3 |
| 8 | VSS | Alimentação | Terra |
| 9 | P4 | Bidirecional | I/O de dados, bit 4 |
| 10 | P5 | Bidirecional | I/O de dados, bit 5 |
| 11 | P6 | Bidirecional | I/O de dados, bit 6 |
| 12 | P7 | Bidirecional | I/O de dados, bit 7 |
| 13 | INT | Saída | Interrupção, ativa em nível baixo, dreno aberto |
| 14 | SCL | Entrada | Clock do barramento I²C |
| 15 | SDA | Bidirecional | Dados do barramento I²C |
| 16 | VDD | Alimentação | Positivo, de 2,5 V a 6 V |

### Características elétricas relevantes

| Parâmetro | Valor | Consequência para o projeto |
|---|---|---|
| Tensão de alimentação | 2,5 V a 6 V | Aceita tanto 3,3 V quanto 5 V |
| Corrente drenada por pino, nível baixo | até 25 mA | Limite de carga por saída |
| Corrente fornecida por pino, nível alto | cerca de 100 µA | Não serve para alimentar carga alguma |
| Corrente total do CI | até 100 mA | Limita o número de saídas simultâneas |
| Velocidade do barramento | até 100 kHz (modo padrão) | Cada byte custa cerca de 0,3 ms |

O detalhe mais importante da tabela é a assimetria entre nível baixo e nível alto. Isso decorre da
estrutura de saída chamada quase bidirecional.

### O que significa "quase bidirecional"

Cada pino Pn tem, internamente, um transistor forte que puxa para o terra e uma fonte de corrente
fraca de 100 microampères que puxa para a alimentação. Quando o pino está em nível alto, ele está
apenas fracamente sustentado, e qualquer coisa externa consegue forçá-lo para baixo. É essa
característica que permite ao mesmo pino servir de entrada e de saída sem configuração de direção.

Para usar um pino como **entrada**, escreve-se 1 nele e depois faz-se a leitura. A fonte fraca
sustenta o nível alto, e um contato externo para o terra vence facilmente a fonte e leva o pino a
nível baixo.

Para usar um pino como **saída**, escreve-se 0 para acionar. A carga deve ser ligada entre a
alimentação e o pino, e o CI a aciona drenando corrente. Esta é a configuração usada no projeto, e é
a origem da lógica invertida no código.

### Endereçamento

O endereço de 7 bits do PCF8574 tem a forma `0100` seguida dos três bits definidos pelos pinos A2,
A1 e A0. Isso dá oito combinações possíveis:

| A2 | A1 | A0 | Endereço |
|---|---|---|---|
| 0 | 0 | 0 | `0x20` |
| 0 | 0 | 1 | `0x21` |
| 0 | 1 | 0 | `0x22` |
| 0 | 1 | 1 | `0x23` |
| 1 | 0 | 0 | `0x24` |
| 1 | 0 | 1 | `0x25` |
| 1 | 1 | 0 | `0x26` |
| 1 | 1 | 1 | `0x27` |

A variante PCF8574A usa o prefixo `0111`, ocupando a faixa de `0x38` a `0x3F`. Combinando os dois
modelos é possível ter dezesseis expansores no mesmo barramento.

Nível baixo em A0, A1 ou A2 significa ligar o pino ao terra. Nível alto significa ligar à
alimentação. Esses pinos não devem ficar flutuando.

> **Este é o ponto do bug do projeto.** No esquemático, A0, A1 e A2 dos três CIs estão no mesmo nó,
> aterrado, o que coloca U1, U2 e U3 todos em `0x20`. Ver
> [09. Pendências, item P1](09-pendencias-e-roadmap.md).

### Protocolo de comunicação

O PCF8574 é o mais simples possível: não tem registradores nem comandos. A transação é apenas o
endereço seguido de um byte de dados.

Para **escrever** nas oito saídas de uma vez:

```
[START] [endereço + bit W=0] [ACK] [byte de dados] [ACK] [STOP]
```

Em Python, com a biblioteca `smbus2`:

```python
from smbus2 import SMBus

bus = SMBus(1)              # I2C1 da Raspberry Pi
bus.write_byte(0x20, 0xFE)  # zera apenas o bit 0, aciona P0
```

Para **ler** as oito entradas de uma vez:

```
[START] [endereço + bit R=1] [ACK] [byte lido] [NACK] [STOP]
```

```python
valor = bus.read_byte(0x20)
```

A consequência prática mais importante é que não existe acesso individual a pino. Toda escrita
sobrescreve os oito bits simultaneamente. Por isso o software precisa manter uma cópia do estado
atual em memória, modificar apenas o bit desejado e reescrever o byte completo. É exatamente o que a
classe `Pcf8574` do projeto faz com o atributo `self.estado`.

### O pino de interrupção

O pino 13, INT, vai a nível baixo sempre que alguma entrada muda de estado, e volta ao normal quando
o mestre faz uma leitura. Ligando esse pino a um GPIO da Raspberry Pi, o software é avisado da
mudança em vez de precisar consultar o expansor repetidamente.

Como é uma saída em dreno aberto, vários CIs podem compartilhar a mesma linha de interrupção, desde
que haja um pull-up. O software então lê os expansores para descobrir qual deles mudou.

No esquemático o INT dos três CIs não chega até a Raspberry Pi, ou seja, o recurso está disponível
mas não foi aproveitado. Como o projeto usa os expansores apenas como saída, isso não é um problema
hoje, mas seria útil caso alguma entrada venha a ser migrada para eles.

## 4.2 L293D, driver de quatro meias-pontes

### Identificação

Fabricado pela STMicroelectronics e por outros, em encapsulamento DIP-16 com abas de dissipação. O
nome de catálogo é "Quadruple Half-H Driver". A versão sem o D, L293, é eletricamente equivalente
mas não inclui os diodos de proteção.

### Pinagem

| Pino | Nome | Direção | Descrição |
|---|---|---|---|
| 1 | EN1 (1,2EN) | Entrada | Habilita os canais 1 e 2 |
| 2 | IN1 (1A) | Entrada | Comando lógico do canal 1 |
| 3 | OUT1 (1Y) | Saída | Saída de potência do canal 1 |
| 4 | GND | Alimentação | Terra e dissipação térmica |
| 5 | GND | Alimentação | Terra e dissipação térmica |
| 6 | OUT2 (2Y) | Saída | Saída de potência do canal 2 |
| 7 | IN2 (2A) | Entrada | Comando lógico do canal 2 |
| 8 | VS (VCC2) | Alimentação | Alimentação de potência, até 36 V |
| 9 | EN2 (3,4EN) | Entrada | Habilita os canais 3 e 4 |
| 10 | IN3 (3A) | Entrada | Comando lógico do canal 3 |
| 11 | OUT3 (3Y) | Saída | Saída de potência do canal 3 |
| 12 | GND | Alimentação | Terra e dissipação térmica |
| 13 | GND | Alimentação | Terra e dissipação térmica |
| 14 | OUT4 (4Y) | Saída | Saída de potência do canal 4 |
| 15 | IN4 (4A) | Entrada | Comando lógico do canal 4 |
| 16 | VSS (VCC1) | Alimentação | Alimentação lógica, de 4,5 V a 7 V |

Os quatro pinos de terra, 4, 5, 12 e 13, são internamente ligados ao dissipador do encapsulamento.
Soldá-los a uma área ampla de cobre é o que permite ao CI trabalhar próximo do limite de corrente.

### Tabela de funcionamento

Cada canal se comporta assim:

| ENn | INn | OUTn |
|---|---|---|
| 0 | qualquer | Alta impedância, desligada |
| 1 | 0 | Nível baixo, conduz para o terra |
| 1 | 1 | Nível alto, conduz da alimentação VS |

O pino de habilitação atua sobre um par de canais: EN1 controla os canais 1 e 2, e EN2 controla os
canais 3 e 4. Com a habilitação em nível baixo, as duas saídas do par ficam desconectadas.

Isso tem uma implicação de projeto que precisa estar clara: não é possível desligar um canal
individualmente pela habilitação, apenas o par. Para apagar um único LED, deve-se levar a entrada IN
correspondente a nível baixo, mantendo a habilitação ativa.

### Características elétricas relevantes

| Parâmetro | Valor | Consequência para o projeto |
|---|---|---|
| Alimentação lógica VSS | 4,5 V a 7 V | Os 5 V usados estão corretos |
| Alimentação de potência VS | até 36 V | Permite carga em tensão maior que a lógica |
| Corrente contínua por canal | 600 mA | Suficiente para LEDs, insuficiente para solenoides |
| Corrente de pico por canal | 1,2 A | Ainda muito abaixo de uma solenoide de flipper |
| Queda no transistor superior | cerca de 1,4 V | Reduz a tensão que chega à carga |
| Queda no transistor inferior | cerca de 1,2 V | Idem |
| Diodos de proteção | internos | Dispensa diodos externos em carga indutiva |

### Sobre a queda de tensão

O L293D é construído com transistores bipolares, que sempre apresentam uma queda de tensão ao
conduzir. Somando os dois transistores de uma meia-ponte, perde-se cerca de 2,6 V internamente.

Com alimentação de 5 V, isso significa que a carga recebe aproximadamente 2,4 V. É um desperdício
considerável, e é a razão pela qual os LEDs do projeto vão acender mais fracos do que o cálculo do
resistor previa, conforme detalhado em
[03. Componentes, seção 3.8](03-componentes.md#38-leds-e-resistores-d1-a-d12-r1-a-r12).

Além de reduzir a tensão útil, essa queda dissipa calor. Um canal conduzindo 600 mA com 1,4 V de
queda dissipa cerca de 0,84 W, e com quatro canais ativos o CI precisa de dissipação adequada. Para
os cerca de 9 mA dos LEDs deste projeto isso é irrelevante, mas vale saber para eventuais mudanças
de carga.

Drivers modernos baseados em MOSFET, como o DRV8871 ou mesmo o TB6612FNG, têm queda muito menor e
seriam a escolha atual para um projeto novo. O L293D permanece útil por disponibilidade e
familiaridade.

### Os diodos internos

Ao interromper a corrente numa carga indutiva, o campo magnético colapsa e a bobina gera um pico de
tensão de polaridade invertida. Sem um caminho para essa corrente, o pico pode chegar a centenas de
volts e destruir o transistor de comando.

Os diodos internos do L293D oferecem esse caminho, chamado de caminho de recirculação. É a razão de
existir a versão com o D no nome, e é o que a torna preferível sempre que a carga é um motor,
solenoide ou relé.

Vale notar que, se as solenoides do projeto vierem a ser acionadas por MOSFETs externos em vez do
L293D, esses diodos de proteção precisarão ser adicionados manualmente ao circuito. É um item que
não pode ser esquecido.

## 4.3 Comparação entre os dois CIs

Os dois integrados são complementares, e entender a divisão de trabalho entre eles é entender a
arquitetura do projeto.

| Aspecto | PCF8574 | L293D |
|---|---|---|
| Função | Multiplicar pinos de I/O | Fornecer potência à carga |
| Interface | Serial I²C, dois fios | Paralela, um pino por canal |
| Consumo de pinos da Pi | 2 para até 8 CIs | 1 por canal |
| Corrente por canal | 25 mA drenando | 600 mA contínuos |
| Latência | Cerca de 0,3 ms por byte | Imediata |
| Papel na cadeia | Decide o que ligar | Executa o acionamento |

A cadeia completa de acionamento fica assim:

```mermaid
flowchart LR
    A["Raspberry Pi<br/>2 pinos de I2C"] -->|"protocolo serial"| B["PCF8574<br/>8 pinos lógicos<br/>25 mA cada"]
    B -->|"nível lógico"| C["L293D<br/>4 canais<br/>600 mA cada"]
    C -->|"potência"| D["Carga<br/>LED ou solenoide"]
```

O PCF8574 resolve a escassez de pinos mas não tem força. O L293D tem força mas consome um pino por
canal. Em cascata, dois pinos da Raspberry Pi comandam dezenas de cargas de potência, que é
exatamente o que uma mesa de pinball exige.

---

Anterior: [03. Componentes](03-componentes.md) ·
Próximo: [05. Pinagem e mapa de I/O](05-pinout.md)

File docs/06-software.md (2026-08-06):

[Voltar ao índice](../README.md)

# 06. Software

## 6.1 Estrutura atual

O código da etapa anterior está em [`upstream/pinball/src`](../upstream/pinball/src) e é enxuto:

```
src/
├── __init__.py
├── main.py                    laço principal, hoje apenas um teste de leitura
├── requeriments.txt           arquivo vazio
└── components/
    ├── __init__.py
    ├── Raspberry.py           classe Raspberry, GPIO e gerência dos expansores
    └── Pcf8574.py             classe Pcf8574, acesso I²C ao expansor
```

O histórico do repositório mostra uma reorganização: existia uma pasta `controllers/` com esboços de
`led.py`, `leds_controller.py`, `l293d_driver.py`, `points_controller.py`, `system_controller.py` e
`network_controller.py`, todos removidos ou vazios. A estrutura convergiu para as duas classes de
acesso ao hardware que sobreviveram. O arquivo `inductive_sensor.py` existe no repositório mas está
vazio.

Vale registrar que o nome `requeriments.txt` está grafado errado, deveria ser `requirements.txt`, e
além disso está vazio. As dependências reais do código são `RPi.GPIO` e `smbus2`.

## 6.2 Classe Pcf8574

Arquivo: [`upstream/pinball/src/components/Pcf8574.py`](../upstream/pinball/src/components/Pcf8574.py)

Encapsula o acesso a um expansor no barramento I²C.

```python
from smbus2 import SMBus

class Pcf8574:
    def __init__(self, barramento=1, endereco=0x20):
        self.barramento = SMBus(barramento)
        self.endereco = endereco
        self.estado = 0b11111111
```

### API

| Método | O que faz |
|---|---|
| `__init__(barramento, endereco)` | Abre o barramento I²C e define o endereço do CI |
| `aciona_saida(pin)` | Zera o bit indicado, acionando a saída |
| `desaciona_saida(pin)` | Coloca o bit indicado em 1, desacionando a saída |
| `get_barramento()` / `set_barramento()` | Acesso ao objeto de barramento |
| `get_endereco()` / `set_endereco()` | Acesso ao endereço configurado |
| `_envia()` | Escreve o byte de estado no CI, uso interno |

### Como funciona o controle de estado

O atributo `self.estado` guarda uma cópia em memória do byte que está nas saídas do CI. Isso é
necessário porque o PCF8574 não permite escrever um pino isoladamente: toda escrita afeta os oito
simultaneamente.

O valor inicial é `0b11111111`, ou seja, todas as saídas em nível alto, que corresponde a todas as
cargas desligadas na lógica adotada.

Acionar uma saída significa zerar o bit correspondente:

```python
self.estado &= ~(1 << pin)   # aciona
self.estado |= (1 << pin)    # desaciona
```

Depois de alterar o bit, `_envia()` transmite o byte completo:

```python
self.barramento.write_byte(self.endereco, self.estado)
```

A lógica está correta. A escolha de acionar com nível baixo é a adequada para o PCF8574, pela
característica quase bidirecional das saídas explicada em
[04. Circuitos integrados](04-circuitos-integrados.md).

### Pontos a melhorar

O método `_envia()` imprime o byte a cada escrita:

```python
literal = f"0b{self.estado:08b}"
print(f"Enviando: {literal}")
```

Isso foi útil na depuração, mas num laço de jogo gera saída em volume alto e custa tempo. Deve virar
uma chamada de `logging` com nível de depuração.

Faltam três coisas para a classe ficar completa. A primeira é um método de leitura, já que o PCF8574
também serve como entrada e a classe hoje só escreve. A segunda é um método para escrever os oito
bits de uma vez, útil para padrões de LED, evitando oito transações onde uma bastaria. A terceira é
tratamento de erro em torno da escrita: se o CI não responder, `write_byte` levanta `OSError`, e no
meio de uma partida isso derruba o programa.

Uma sugestão de complemento:

```python
import logging

log = logging.getLogger(__name__)

class Pcf8574:
    def le_entradas(self) -> int:
        """Lê os oito pinos de uma vez e devolve o byte."""
        return self.barramento.read_byte(self.endereco)

    def escreve_byte(self, valor: int) -> None:
        """Define os oito pinos de uma vez."""
        self.estado = valor & 0xFF
        self._envia()

    def _envia(self) -> None:
        log.debug("PCF 0x%02X <- 0b%08b", self.endereco, self.estado)
        try:
            self.barramento.write_byte(self.endereco, self.estado)
        except OSError as e:
            log.error("Falha ao escrever no PCF 0x%02X: %s", self.endereco, e)
            raise
```

## 6.3 Classe Raspberry

Arquivo: [`upstream/pinball/src/components/Raspberry.py`](../upstream/pinball/src/components/Raspberry.py)

Cuida dos GPIOs e mantém a lista de expansores conectados.

```python
class Raspberry:
    def __init__(self):
        self.pcfs = []
        self.entradas = [
            4, 17, 27, 22, 5, 6, 13, 19,
            26, 23, 24, 25, 12, 16, 20, 21
        ]
        GPIO.setmode(GPIO.BCM)
```

### API

| Método | O que faz |
|---|---|
| `carregar_entradas()` | Configura os 16 GPIOs como entrada com pull-up |
| `ler_entrada(pin)` | Lê um GPIO, validando se ele está na lista de entradas |
| `scan()` | Lê todas as entradas e devolve um dicionário GPIO para estado |
| `adiciona_modulo(endereco)` | Instancia um `Pcf8574` e o guarda na lista |
| `get_pcf(endereco)` | Recupera um expansor já criado pelo endereço |
| `cleanup()` | Libera os GPIOs, chamando `GPIO.cleanup()` |

### Um problema no método scan

O método está assim:

```python
def scan(self) -> dict:
    self.carregar_entradas()
    estados = {p: GPIO.input(p) for p in self.entradas}
    return estados
```

A chamada a `carregar_entradas()` dentro do `scan()` reconfigura os 16 pinos a cada varredura.
Como o `main.py` chama `scan()` dentro de um laço sem pausa, o resultado é que os 16 pinos são
reconfigurados milhares de vezes por segundo. Isso desperdiça CPU e, mais importante, cada
reconfiguração momentaneamente solta o pull-up interno, o que pode gerar leituras falsas.

A configuração pertence à inicialização, não à leitura:

```python
def __init__(self):
    self.pcfs = []
    self.entradas = [...]
    GPIO.setmode(GPIO.BCM)
    self.carregar_entradas()      # uma vez só

def scan(self) -> dict:
    return {p: GPIO.input(p) for p in self.entradas}
```

### Outros pontos

O `adiciona_modulo` fixa o barramento 1 na chamada, `Pcf8574(1, endereco)`, ignorando um possível
parâmetro. Como a Raspberry Pi usa `I2C1` de fato, funciona, mas seria mais limpo tornar isso um
atributo da classe.

O tratamento de erro captura a exceção e devolve `None` com uma mensagem impressa. Quem chama pode
seguir com um `None` sem perceber, e o erro aparece mais tarde em outro lugar. Para inicialização de
hardware é melhor deixar a exceção subir, porque um expansor ausente é uma falha que impede o jogo
de funcionar.

O método `cleanup()` existe mas nunca é chamado no `main.py`. Sem ele, os GPIOs ficam no último
estado após o programa terminar, e a biblioteca emite avisos na execução seguinte.

## 6.4 O main atual

Arquivo: [`upstream/pinball/src/main.py`](../upstream/pinball/src/main.py)

```python
from components.Raspberry import Raspberry
import time

def main():
    rasp = Raspberry()
    pcf = rasp.adiciona_modulo(0x27)

    while True:
        estados = rasp.scan()
        print("Entradas:", estados)

if __name__ == "__main__":
    main()
```

É um teste de leitura, não um jogo. Ele lê as 16 entradas e imprime, indefinidamente.

Três observações. O `import time` não é usado, e o laço não tem pausa alguma, o que faz o processo
consumir 100% de um núcleo e produzir saída ilegível. O `pcf` é criado e nunca usado. E o endereço
`0x27` diverge do esquemático, conforme discutido em [05. Pinagem](05-pinout.md).

Uma versão mínima mais útil para diagnóstico, mostrando apenas mudanças:

```python
import time
from components.Raspberry import Raspberry

def main():
    rasp = Raspberry()
    anterior = rasp.scan()
    print("Estado inicial:", anterior)

    try:
        while True:
            atual = rasp.scan()
            for pino, valor in atual.items():
                if valor != anterior[pino]:
                    estado = "ACIONADO" if valor == 0 else "liberado"
                    print(f"GPIO{pino}: {estado}")
            anterior = atual
            time.sleep(0.005)
    except KeyboardInterrupt:
        pass
    finally:
        rasp.cleanup()

if __name__ == "__main__":
    main()
```

Esse programa serve diretamente para levantar a tabela de mapeamento de sensores pendente em
[05. Pinagem, seção 5.2](05-pinout.md#52-mapeamento-sensor-para-gpio): aciona-se um sensor por vez e
o terminal informa qual GPIO respondeu.

## 6.5 Preparando a Raspberry Pi

O I²C não vem habilitado por padrão. Para ativar:

```bash
sudo raspi-config
# Interface Options, I2C, Yes
sudo reboot
```

Confirmando que o barramento existe e que os CIs respondem:

```bash
sudo apt install -y i2c-tools python3-pip
i2cdetect -y 1
```

A saída mostra os endereços encontrados. Com os três expansores corretamente endereçados, devem
aparecer `20`, `21` e `22`. Com o esquemático como está, aparecerá apenas `20`, e é assim que se
confirma na prática o problema descrito em [P1](09-pendencias-e-roadmap.md).

Instalando as dependências:

```bash
pip3 install RPi.GPIO smbus2
```

Executando:

```bash
cd src
python3 main.py
```

O `main.py` importa como `from components.Raspberry import ...`, então precisa ser executado de
dentro de `src/`, e não da raiz do repositório.

## 6.6 Arquitetura de software recomendada

O relatório da etapa anterior descreve a evolução do raciocínio da equipe. Começaram com um laço
sequencial, perceberam que não dava conta de tratar sensores, solenoides, LEDs e pontuação ao mesmo
tempo, passaram a usar threads, e concluíram que o caminho correto seria um modelo de tarefas ao
estilo RTOS, com a Raspberry Pi cuidando do alto nível e um ESP32 cuidando do tempo real.

Essa conclusão é sólida, e a razão é concreta. O flipper precisa responder ao botão em poucos
milissegundos, de forma consistente. O Linux não garante isso: sob carga, o escalonador pode atrasar
uma thread por dezenas de milissegundos, e o jogador percebe o flipper falhando de forma aleatória.
Além disso, o tempo de acionamento de uma solenoide tem que ser respeitado com precisão, sob risco de
queimar a bobina.

A divisão sugerida é a seguinte.

```mermaid
flowchart TB
    subgraph ESP["ESP32 com FreeRTOS, tempo real"]
        T1["Tarefa: flippers<br/>lê botão, pulsa solenoide<br/>prioridade máxima"]
        T2["Tarefa: bumpers<br/>lê sensor, pulsa solenoide"]
        T3["Tarefa: proteção<br/>garante tempo máximo<br/>de acionamento"]
    end

    subgraph RPI["Raspberry Pi, alto nível"]
        G1["Máquina de estados<br/>do jogo"]
        G2["Pontuação e recordes"]
        G3["LEDs cênicos e áudio"]
        G4["Placar em tela"]
    end

    T1 -->|"evento: alvo atingido"| G1
    T2 -->|"evento: bumper"| G1
    G1 --> G2
    G1 -->|"comando: acender padrão"| G3
    G2 --> G4
    G1 -->|"comando: lançar bola"| ESP
    RPI <-->|"UART ou I2C"| ESP
```

O ESP32 fica com tudo que tem prazo curto: ler o botão do flipper e pulsar a solenoide, detectar o
bumper e responder, e garantir por conta própria que nenhuma solenoide fique energizada além do
tempo seguro. A Raspberry Pi fica com o que não tem urgência de milissegundos: a máquina de estados
da partida, pontuação, efeitos de luz, som e placar.

A comunicação entre os dois pode ser UART, usando GPIO14 e GPIO15 que estão livres, com um protocolo
simples de mensagens de evento e de comando.

### Se a decisão for manter tudo na Raspberry Pi

É viável para uma primeira versão jogável, com duas ressalvas de implementação.

Para os sensores, usar detecção de evento por interrupção em vez de varredura, o que resolve
latência e repique de uma vez:

```python
GPIO.add_event_detect(pino, GPIO.FALLING,
                      callback=trata_sensor,
                      bouncetime=50)   # ignora repique por 50 ms
```

Para as solenoides, garantir o desligamento com um bloco `finally`, que executa mesmo se algo falhar
no meio:

```python
import time

TEMPO_PULSO = 0.04   # 40 ms

def pulsa_solenoide(pcf, pino):
    pcf.aciona_saida(pino)
    try:
        time.sleep(TEMPO_PULSO)
    finally:
        pcf.desaciona_saida(pino)
```

Ainda assim, esse `time.sleep` pode ser esticado pelo escalonador, e é por isso que a proteção em
hardware descrita em [P2](09-pendencias-e-roadmap.md) continua sendo necessária.

## 6.7 Estrutura de código sugerida

Uma organização que separa acesso ao hardware da lógica do jogo:

```
src/
├── main.py                    ponto de entrada
├── requirements.txt
├── hardware/
│   ├── raspberry.py           GPIO e barramento
│   ├── pcf8574.py             expansor
│   ├── sensor.py              abstrai um sensor, com nome e evento
│   └── solenoide.py           abstrai uma solenoide, com pulso e proteção
├── jogo/
│   ├── estados.py             máquina de estados da partida
│   ├── pontuacao.py           regras de pontuação e recordes
│   └── efeitos.py             padrões de LED e som
└── config/
    └── mapa_io.py             tabela única de mapeamento de pinos
```

A ideia central do `mapa_io.py` é ter um único lugar no código onde o mapeamento físico está
declarado, em vez de números de pino espalhados pela lógica:

```python
# config/mapa_io.py

ENDERECOS_PCF = {
    "solenoides_1": 0x20,
    "solenoides_2": 0x21,
    "leds": 0x22,
}

SENSORES = {
    "flipper_esquerdo": 5,
    "flipper_direito":  6,
    "botao_start":     12,
    "dreno":           17,
    # completar conforme o levantamento da seção 5.2
}

SOLENOIDES = {
    "flipper_esquerdo": ("solenoides_1", 0),
    "flipper_direito":  ("solenoides_1", 1),
    "injetor":          ("solenoides_1", 2),
    # completar
}
```

Com isso, mudar uma ligação física exige editar uma linha, e a lógica do jogo passa a falar em nomes
como `flipper_esquerdo` em vez de `GPIO5`.

---

Anterior: [05. Pinagem e mapa de I/O](05-pinout.md) · Próximo: [07. Mecânica](07-mecanica.md)

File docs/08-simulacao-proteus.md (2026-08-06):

[Voltar ao índice](../README.md)

# 08. Simulação no Proteus

## 8.1 Por que simular

A equipe anterior optou por validar o circuito no Proteus antes de montar, com dois objetivos.
O primeiro foi confirmar que a comunicação I²C entre a Raspberry Pi e o PCF8574 funcionava como
esperado. O segundo foi verificar a expansão de GPIO e o acionamento de cargas sem risco de queimar
componentes.

É uma abordagem correta, e vale notar que a simulação é justamente onde o problema de endereçamento
descrito em [P1](09-pendencias-e-roadmap.md) passou sem ser detectado. O Proteus não reclama de dois
CIs no mesmo endereço porque o circuito simulado usava apenas um expansor de cada vez.

## 8.2 O arquivo de projeto

O projeto está em
[`upstream/pinball/hardware/diagrama-pinball.pdsprj`](../upstream/pinball/hardware/diagrama-pinball.pdsprj).

O `.pdsprj` é um contêiner compactado. Seu conteúdo interno é:

| Arquivo | Conteúdo |
|---|---|
| `ROOT.DSN` | Esquemático, no formato ISIS |
| `ROOT.LYT` | Layout de placa, praticamente vazio |
| `ROOT.CDB` | Dados de configuração do projeto |
| `PROJECT.XML` | Metadados, versão e scripts |
| `FIRMWARE.XML` | Declara a família Raspberry Pi, compilador Python 3, tipo RPI4 |
| `FIRMWARE/Raspberry Pi 4/main.py` | Código Python executado na simulação |
| `SCRIPTS/PWRRAILS.DAT` | Definição de trilhas de alimentação |

Dois pontos vale registrar. O primeiro é que o layout de placa não foi desenvolvido, apenas o
esquemático, então não existe PCB projetada. O segundo é que existe um `main.py` dentro do projeto do
Proteus que não está versionado em `src/`, e é diferente do código do repositório.

## 8.3 O firmware da simulação

O código que roda dentro do Proteus é este:

```python
import smbus
import time

DEVICE_ADDRESS = 0x20   # confirme com i2cdetect

bus = smbus.SMBus(1)    # 1 = bus I2C do RPi (I2C1)

def write_pcf8574(valor):
    bus.write_byte(DEVICE_ADDRESS, valor)

try:
    estado = 0x01       # bit 0 ativo
    while True:
        write_pcf8574(estado)
        estado ^= 0x01  # alterna bit 0
        time.sleep(1)

except KeyboardInterrupt:
    write_pcf8574(0x00)
```

É um teste de vida: alterna o bit 0 do expansor a cada segundo, o que na prática faz um LED piscar.
Serve para confirmar que o barramento está funcionando de ponta a ponta.

Duas diferenças em relação ao código do repositório merecem atenção. Este usa o endereço `0x20`,
coerente com o esquemático, enquanto `src/main.py` usa `0x27`. E este usa a biblioteca `smbus`,
enquanto o repositório usa `smbus2`. As duas têm API compatível para as operações usadas aqui, mas a
`smbus2` é a mantida atualmente e é a escolha correta.

O relatório traz ainda uma variante desse mesmo teste, que além de escrever também lê de volta:

```python
import smbus
import time

PCF_ADDR = 0x20
bus = smbus.SMBus(1)
estado = 0xFF

bus.write_byte(PCF_ADDR, estado)
print("Iniciando teste com PCF8574...")

while True:
    estado ^= 0x01
    bus.write_byte(PCF_ADDR, estado)
    print(f"Estado enviado: {bin(estado)}")

    leitura = bus.read_byte(PCF_ADDR)
    print(f"Leitura do PCF8574: {bin(leitura)}")

    time.sleep(1)
```

A leitura de volta é uma boa prática de diagnóstico: se o valor lido não corresponder ao escrito, ou
o CI não está respondendo, ou existe algo externo forçando o nível de um pino.

## 8.4 Como abrir e rodar

Requisitos: Proteus 8.10 ou superior, com a biblioteca da Raspberry Pi instalada. O suporte a
Raspberry Pi no Proteus é um recurso das versões mais recentes.

O procedimento é o seguinte.

1. Clonar este repositório com o submódulo, conforme instruções do [README](../README.md).
2. Abrir `upstream/pinball/hardware/diagrama-pinball.pdsprj` no Proteus.
3. O esquemático abre na aba principal, e o código Python fica visível na aba de projeto de firmware.
4. Iniciar a simulação com o botão de play, ou tecla F12.

Durante a simulação, os elementos interativos disponíveis são os atuadores de estado lógico ligados
aos pinos EN1 e EN2 dos L293D, que aparecem como blocos com o valor `0` e setas para alternar. As
chaves de fim de curso e os sensores indutivos também podem ser acionados clicando neles.

O que se observa é o LED ligado ao bit 0 piscando a cada segundo, confirmando que a Raspberry Pi
simulada está escrevendo no expansor e que o expansor está acionando a saída.

## 8.5 Limites da simulação

Vale ter clareza sobre o que essa simulação não prova, para não criar falsa confiança.

Ela não testa endereçamento múltiplo. O firmware fala com um único endereço, então o conflito entre
U1, U2 e U3 nunca se manifesta. Foi assim que o problema passou.

Ela não testa as solenoides, que aparecem no esquemático como símbolos sem modelo atribuído. Ou seja,
a parte mais crítica do acionamento não foi simulada.

Ela não representa o comportamento elétrico real. O Proteus modela componentes ideais em muitos
aspectos, e não reproduz ruído de chaveamento, queda em cabos longos, nem a interferência que uma
solenoide de vários ampères injeta no sistema ao desligar. Numa mesa de pinball, com cabeamento longo
passando perto de bobinas, esse é justamente o tipo de problema que aparece na bancada e não na
simulação.

Ela não representa o comportamento temporal do Linux. A simulação executa o Python de forma
determinística, o que esconde exatamente o problema de latência que motivou a proposta de migrar para
um RTOS.

O relatório menciona que na bancada houve falhas intermitentes no reconhecimento de sensores e
dificuldades no I²C, problemas que a simulação não antecipou. A combinação de conflito de endereço,
níveis de 5 V contra 3,3 V e ruído de cabeamento explica bem esses sintomas.

## 8.6 Referências usadas pela equipe anterior

O relatório cita como material de apoio a documentação da Labcenter Electronics sobre simulação de
Raspberry Pi no Proteus, e um vídeo demonstrativo do mesmo tema.

---

Anterior: [07. Mecânica](07-mecanica.md) ·
Próximo: [09. Pendências e roadmap](09-pendencias-e-roadmap.md)

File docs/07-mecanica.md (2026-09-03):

[Voltar ao índice](../README.md)

# 07. Mecânica

O histórico deste documento vem do relatório da etapa anterior,
[`Projeto_Integrador_II___Pinball.pdf`](../upstream/pinball/Projeto_Integrador_II___Pinball.pdf).
O novo modelo paramétrico do mecanismo do flipper está versionado em
[`mecanica/modelos-3d`](../mecanica/modelos-3d/README.md). Os arquivos usados para fabricar as demais
peças originais ainda não foram recuperados, conforme registrado em
[P11](09-pendencias-e-roadmap.md).

## 7.1 Processo de projeto

O trabalho seguiu quatro etapas.

A concepção começou no **Tinkercad**, com um modelo tridimensional completo do pinball. O objetivo
era visualizar a disposição interna dos elementos e definir proporções antes de detalhar qualquer
peça.

O detalhamento passou para o **AutoCAD**, para o projeto da estrutura da mesa. A escolha se justifica
pela precisão dimensional maior, e as medidas foram tiradas de um modelo físico de pinball já
existente, o que ajudou a acertar proporções que são difíceis de estimar do zero.

Os obstáculos internos voltaram ao Tinkercad para modelagem individual.

A fabricação foi por **impressão 3D**, com ciclos de impressão, teste, ajuste e reimpressão.

## 7.2 Peças e origens

| Peça | Origem | Situação |
|---|---|---|
| Estrutura da mesa | Projeto próprio no AutoCAD, medidas de um pinball físico | Projetada |
| Bumpers | Adaptação de [modelo do Cults3D](https://cults3d.com/) | Impressos |
| Flippers, primeira tentativa | Modelo de referência do Cults3D | Descartada |
| Flippers, versão final | Modelagem a partir de vídeos do canal Daniele Tartaglia | Impressos |
| Injetor, primeira versão | Modelo do Thingiverse | Descartada, desempenho insuficiente |
| Injetor, segunda versão | Outro modelo do Thingiverse | Impresso, funcionamento adequado |
| Repositor de bolas | Vídeos do canal Daniele Tartaglia | Impresso |

Para os flippers e o repositor de bolas, a equipe usou a ferramenta **Hitem3D** (`hitem3d.ai`), que
gera modelos 3D a partir de imagens. A abordagem foi capturar imagens dos projetos mostrados nos
vídeos de referência e converter em malha aproveitável.
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

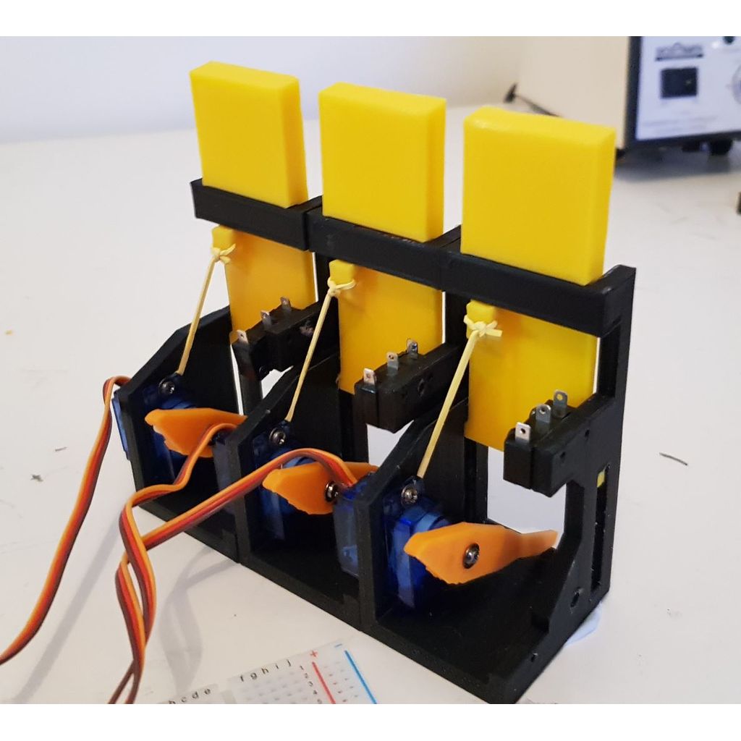
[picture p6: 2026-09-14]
mecanica/modelos-3d/drop-target/references/image.jpg

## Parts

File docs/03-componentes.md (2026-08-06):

[Voltar ao índice](../README.md)

# 03. Componentes

Este documento descreve cada componente presente no esquemático: o que é, por que foi escolhido,
como funciona e qual o papel dele no pinball. As referências de designador (U1, D1, CF01 e assim
por diante) são as mesmas usadas no esquemático do Proteus.

## 3.1 Lista de materiais

| Designador | Componente | Qtd. | Função no pinball |
|---|---|---|---|
| RB01 | Raspberry Pi 4 | 1 | Unidade central de processamento |
| U1, U2, U3 | PCF8574 | 3 | Expansor de I/O digital via I²C |
| U4, U5, U6 | L293D | 3 | Driver de potência para as cargas |
| SI01 a SI03 | LJ12A3-4-Z/BX | 3 | Sensor indutivo de presença da bola |
| CF01 a CF10 | KW11-3Z-3 | 10 | Chave de fim de curso, alvos e botões |
| SL01 a SL10 | Solenoide | 10 | Atuador dos flippers, bumpers e injetor |
| D1 a D12 | LED vermelho 5 mm | 12 | Iluminação cênica |
| R1 a R12 | Resistor 180 Ω | 12 | Limitação de corrente dos LEDs |
| RN1, RN2 | Rede resistiva 8x10 kΩ | 2 | Pull-up nas entradas dos drivers |
| RN3 | Rede resistiva 8x10 kΩ | 1 | Pull-up nas entradas de sensor |
| BAT1, BAT2 | Fonte 5 V | 2 | Alimentação de lógica e de potência |
| BAT3 | Fonte 3,3 V | 1 | Referência dos pull-ups de entrada |

## 3.2 Raspberry Pi 4 (RB01)

### O que é

Um computador de placa única com SoC Broadcom BCM2711, quatro núcleos Cortex-A72, rodando Linux
completo. No esquemático aparece como o modelo `RPI4` do Proteus, que expõe o conector de 40 pinos.

### Por que foi escolhida

O relatório da etapa anterior justifica a escolha por três razões. A primeira é rodar Python
diretamente, sem toolchain de compilação cruzada, o que acelera o desenvolvimento. A segunda é ter
I²C e SPI nativos no cabeçalho de pinos. A terceira é abrir caminho para recursos de alto nível
mais adiante, como um placar em tela, áudio e registro de recordes em banco de dados.

### Como é usada no projeto

A Pi tem dois papéis distintos no esquemático.

Como leitora de sensores, ela dedica 16 GPIOs configurados como entrada com pull-up interno.
Treze deles estão ocupados pelos sensores e três ficam de reserva. É o caminho de menor latência
disponível, e é por isso que os sensores não passam pelos expansores.

Como mestre do barramento I²C, ela usa GPIO2 e GPIO3 (pinos físicos 3 e 5) para comandar os três
PCF8574, que por sua vez acionam solenoides e luzes.

A pinagem completa está em [05. Pinagem e mapa de I/O](05-pinout.md).

### Limitações relevantes

Os GPIOs trabalham em 3,3 V e não toleram 5 V. Aplicar 5 V numa entrada danifica o SoC de forma
permanente. Isso é crítico aqui porque os PCF8574 do esquemático estão alimentados em 5 V.

A corrente por GPIO é limitada a cerca de 16 mA, com um total de aproximadamente 50 mA somando
todos os pinos. Não há folga para acionar carga alguma diretamente, o que reforça a necessidade dos
drivers.

O Linux não é um sistema de tempo real. O escalonador pode atrasar a execução de um trecho de código
por dezenas de milissegundos sob carga. Para o placar isso é irrelevante, mas para o flipper é o
problema central que motivou a proposta de migrar o tempo real para um microcontrolador dedicado.

## 3.3 PCF8574 (U1, U2, U3)

### O que é

Um expansor de I/O de 8 bits com interface I²C, em encapsulamento DIP ou SO de 16 pinos. Converte
duas linhas do barramento serial em oito pinos digitais quase bidirecionais.

O tratamento detalhado do CI, com pinagem, protocolo e tabela de endereços, está em
[04. Circuitos integrados](04-circuitos-integrados.md). Aqui fica o papel dele no pinball.

### Por que foi escolhido

A conta de I/O do projeto não fecha com os pinos da Raspberry Pi. São necessários mais de 20 pontos
de saída, além dos 13 de entrada já ocupados. Cada PCF8574 acrescenta 8 pinos consumindo apenas as
duas linhas do I²C que já existiam, e é possível colocar até oito unidades no mesmo barramento. O CI
é barato, amplamente disponível e a biblioteca `smbus2` do Python fala com ele em uma linha de
código.

### Como é usado no projeto

A intenção do projeto, conforme o esquemático, distribui as saídas assim:

| CI | Pinos | Destino |
|---|---|---|
| U1 | P0 a P7 | Solenoides SL01 a SL08 |
| U2 | P0 e P1 | Solenoides SL09 e SL10 |
| U2 | P2 a P7 | Entradas de comando dos L293D |
| U3 | P0 a P7 | Entradas de comando dos L293D |

O acionamento é por nível baixo. A classe `Pcf8574` do projeto mantém uma cópia do byte de estado em
memória, começando em `0b11111111`, e para acionar uma saída ela zera o bit correspondente e
reescreve o byte inteiro. Isso é necessário porque o PCF8574 não permite escrever um pino
isoladamente: toda escrita afeta os oito de uma vez.

### Limitações relevantes

A corrente que o PCF8574 pode fornecer em nível alto é de apenas 100 microampères, vinda de uma
fonte de corrente interna. Em nível baixo ele drena até 25 mA por pino. A consequência prática é que
qualquer carga deve ser ligada entre a alimentação e o pino, para que o CI a acione drenando
corrente, e não fornecendo. Isso explica a lógica invertida adotada no código.

O barramento I²C na Raspberry Pi opera tipicamente a 100 kHz. Cada escrita de byte consome cerca de
0,3 ms entre endereçamento e confirmação. Acionar um flipper por essa via, portanto, custa uma
fração de milissegundo apenas na transmissão, sem contar o atraso do agendador do Linux.

O CI oferece um pino INT que sinaliza mudança nas entradas, dispensando leitura por varredura. No
esquemático o pino 13 (INT) dos três CIs aparece com uma conexão que não é levada até a Raspberry
Pi, ou seja, o recurso está disponível mas não foi aproveitado.

## 3.4 L293D (U4, U5, U6)

### O que é

Um driver de quatro meias-pontes em um encapsulamento de 16 pinos, capaz de fornecer 600 mA
contínuos por canal, com pico de 1,2 A. A letra D no final indica que o CI já traz diodos de
proteção internos contra a tensão reversa gerada por cargas indutivas.

O tratamento detalhado está em [04. Circuitos integrados](04-circuitos-integrados.md).

### Por que foi escolhido

É o CI de acionamento mais comum em laboratórios de ensino, provavelmente já disponível no
almoxarifado do campus. Ele resolve o problema de o PCF8574 não ter corrente para carga alguma,
aceita nível lógico direto nas entradas e, por ter os diodos internos, dispensa componentes
adicionais quando a carga é indutiva.

### Como é usado no projeto

No esquemático os três L293D acionam exclusivamente os LEDs. Cada CI tem quatro canais, e são doze
LEDs no total.

| CI | Saídas | LEDs |
|---|---|---|
| U4 | OUT1 a OUT4 | D1 a D4 |
| U5 | OUT1 a OUT4 | D5 a D8 |
| U6 | OUT1 a OUT4 | D9 a D12 |

O comando de cada canal vem de um pino de PCF8574 ligado à entrada IN correspondente. Quando a
entrada vai a nível alto, a saída conduz e o LED acende.

### Como o relatório pretendia usá-lo

O relatório da etapa anterior afirma que os L293D serviriam de driver tanto para os LEDs quanto para
as solenoides dos bumpers e flippers. O esquemático, porém, só implementa o caminho dos LEDs: as
solenoides SL01 a SL10 estão ligadas direto nos pinos dos PCF8574, sem estágio de potência algum.

Essa é uma divergência importante entre a intenção documentada e o circuito desenhado, e ela precisa
ser resolvida antes de qualquer montagem. Vale registrar também que o L293D não é adequado para
solenoides de pinball: 600 mA por canal fica muito abaixo dos vários ampères que uma solenoide de
flipper exige, e a tensão máxima de 36 V limita as opções de fonte. Ver
[P2](09-pendencias-e-roadmap.md).

### Limitações relevantes

O L293D é um driver bipolar, e por isso tem queda de tensão considerável: cerca de 1,4 V no
transistor superior e 1,2 V no inferior, somando aproximadamente 2,6 V perdidos internamente. Com
alimentação de 5 V, sobram cerca de 2,4 V para a carga, o que é suficiente para um LED vermelho mas
inviabiliza cargas mais exigentes.

Essa queda também gera calor. Com quatro canais ativos, o encapsulamento precisa de dissipação, o
que na prática significa deixar as abas de terra soldadas a uma área de cobre generosa.

## 3.5 Sensor indutivo LJ12A3-4-Z/BX (SI01 a SI03)

### O que é

Um sensor de proximidade indutivo cilíndrico de rosca M12, que detecta a presença de metal a uma
distância nominal de 4 mm sem contato físico. A designação decompõe-se assim: `LJ12` indica o
diâmetro de 12 mm, `A3` é a série, `4` é a distância de detecção em milímetros, `Z/BX` indica saída
NPN normalmente aberta.

O princípio de funcionamento é uma bobina que gera um campo magnético alternado na face do sensor.
Quando um objeto metálico entra nesse campo, correntes parasitas induzidas no metal amortecem a
oscilação, e o circuito interno detecta essa queda de amplitude e comuta a saída.

### Por que foi escolhido

A bola de pinball é de metal, o que dispensa qualquer refletor ou marcação. Como não há contato
mecânico, não existe peça para desgastar nem contato para oxidar, e o sensor é imune a poeira e
iluminação ambiente, ao contrário de uma solução óptica. Também é um dos sensores industriais mais
baratos e comuns no mercado brasileiro.

### Como é usado no projeto

Os três sensores detectam a passagem da bola em pontos específicos da mesa. Os usos típicos são
confirmar que a bola foi injetada e está em jogo, detectar passagem por rampas ou túneis para
pontuar, e detectar que a bola caiu no dreno para encerrar a bola atual.

Eletricamente eles são ligados como contato para o terra. A saída NPN conduz para o terra quando
detecta metal, e a rede de pull-up RN3, referenciada em 3,3 V, mantém a linha em nível alto quando
não há detecção. O GPIO da Raspberry Pi lê nível baixo como bola detectada.

### Cuidado importante de tensão

Este é o ponto de atenção mais relevante deste componente. O LJ12A3-4-Z/BX é especificado para
alimentação entre 6 V e 36 V, tipicamente 12 V ou 24 V. A saída em coletor aberto de um sensor
alimentado em 24 V, se conectada diretamente a um GPIO da Raspberry Pi, aplicaria 24 V no pino e
destruiria o SoC.

O esquemático evita isso ao usar RN3 puxando para 3,3 V, o que é a topologia correta: o transistor
de saída do sensor só puxa para baixo, e quem define o nível alto é o pull-up em 3,3 V. Para que
isso realmente funcione na montagem física, a saída do sensor precisa ser genuinamente coletor
aberto, sem nenhum caminho interno para a alimentação de 24 V. Vale medir com o multímetro antes de
ligar na Pi. Ver [P4](09-pendencias-e-roadmap.md).

## 3.6 Chave de fim de curso KW11-3Z-3 (CF01 a CF10)

### O que é

Uma microchave de ação rápida, do tipo comumente chamado de microswitch, com haste ou alavanca
acionadora. O modelo KW11-3Z-3 é a versão com alavanca longa, três terminais (comum, normalmente
aberto e normalmente fechado) e mecanismo de mola que produz comutação rápida e com histerese.

### Por que foi escolhida

É o componente clássico de pinball, usado nas máquinas comerciais desde sempre, tanto nos alvos
quanto nos botões dos flippers. É extremamente barata, aceita milhões de ciclos, e o clique
mecânico dá retorno tátil ao jogador. A ação rápida também produz uma borda de sinal limpa, o que
ajuda na detecção por software.

### Como é usada no projeto

São dez unidades no esquemático, distribuídas em dois grupos. As oito primeiras, CF01 a CF08,
ficam no bloco à esquerda e vão diretamente para GPIOs, sem pull-up externo, dependendo do pull-up
interno da Pi. As duas últimas, CF09 e CF10, ficam no bloco superior junto dos sensores indutivos e
compartilham a rede de pull-up RN3 em 3,3 V.

Os papéis previstos no jogo são os alvos que pontuam quando a bola os atinge, os botões dos flippers
acionados pelo jogador, o botão de início de partida, e o monitoramento de posição de mecanismos,
por exemplo confirmar que o injetor voltou ao repouso.

O esquemático não identifica qual chave cumpre qual papel. Isso é uma lacuna a resolver na montagem
e está registrado em [P7](09-pendencias-e-roadmap.md).

### O problema do repique

Todo contato mecânico apresenta repique, ou bounce: nos primeiros milissegundos após o fechamento,
o contato abre e fecha várias vezes antes de estabilizar. Sem tratamento, o software conta um único
toque do jogador como cinco ou dez acionamentos, e a pontuação fica errada.

O tratamento pode ser feito em hardware, com um filtro RC seguido de um Schmitt trigger, ou em
software, ignorando novas transições dentro de uma janela de tempo. A biblioteca `RPi.GPIO` já
oferece o parâmetro `bouncetime` no método `add_event_detect`, que resolve o problema de forma
direta. O código atual não trata repique, porque ainda não implementa detecção de eventos. Está
registrado em [P9](09-pendencias-e-roadmap.md).

## 3.7 Solenoides (SL01 a SL10)

### O que são

Atuadores eletromagnéticos lineares. Uma bobina envolve um núcleo de ferro móvel, e ao ser
energizada gera um campo que puxa o núcleo para dentro com força considerável. Quando desenergizada,
uma mola devolve o núcleo à posição de repouso.

### Por que são usadas

A solenoide é o atuador padrão do pinball porque entrega um golpe forte e rápido em movimento
linear, exatamente o que se precisa para arremessar a bola. Um motor exigiria mecanismo de conversão
de movimento e responderia mais lentamente.

### Como seriam usadas no projeto

São dez solenoides previstas, distribuídas entre três funções. Duas acionam os flippers, respondendo
aos botões do jogador com o menor atraso possível. Algumas acionam os bumpers, disparando quando um
sensor detecta que a bola encostou no obstáculo. E uma aciona o injetor, que coloca a bola em jogo
no início de cada rodada.

### Estado atual no esquemático

As dez solenoides aparecem no esquemático como símbolos genéricos sem modelo atribuído, ligadas
diretamente aos pinos dos PCF8574. Isso significa que o estágio de acionamento não foi projetado, e
o circuito como está não pode ser montado: um pino de PCF8574 drena no máximo 25 mA, enquanto uma
solenoide de flipper puxa vários ampères.

### O que precisa ser projetado

O acionamento de uma solenoide de pinball envolve três coisas que faltam no circuito atual.

A primeira é o estágio de potência. Um MOSFET de canal N com resistência de condução baixa, ou um
módulo de driver de alta corrente, comandado pelo pino do PCF8574. O MOSFET deve ser dimensionado
para a corrente de pico da solenoide, com folga.

A segunda é a proteção contra tensão reversa. Ao desligar uma bobina, o colapso do campo magnético
gera um pico de tensão que pode chegar a centenas de volts e destrói o transistor de comando. Um
diodo de recuperação rápida em antiparalelo com a bobina resolve, e é obrigatório.

A terceira é a limitação de tempo de acionamento. Uma solenoide de pinball é projetada para pulsos
curtos, tipicamente entre 30 ms e 50 ms. Se ficar energizada continuamente, a bobina superaquece e
queima em segundos. O software precisa garantir o desligamento, e é boa prática ter também uma
proteção em hardware que corte o acionamento independentemente do software. Este ponto é o mais
crítico da lista, porque uma falha de software aqui significa dano físico.

Tudo isso está detalhado em [P2](09-pendencias-e-roadmap.md).

## 3.8 LEDs e resistores (D1 a D12, R1 a R12)

### O que são

Doze LEDs vermelhos de 5 mm, cada um em série com um resistor de 180 ohms, acionados pelas saídas
dos três L293D.

### Como são usados

A função é a iluminação cênica da mesa: piscar no modo atração para chamar a atenção, dar retorno
visual quando um alvo é atingido, e indicar estados do jogo como bola em jogo ou fim de partida.

### Sobre o valor do resistor

O cálculo do resistor parte da tensão disponível, da queda no LED e da corrente desejada. Um LED
vermelho de 5 mm tem queda de cerca de 2 V e opera bem em 20 mA.

Se a saída do L293D entregasse os 5 V da alimentação, a conta seria a seguinte:

```
R = (5 V - 2 V) / 20 mA = 150 Ω
```

O valor de 180 ohms escolhido é o valor comercial imediatamente acima, uma escolha conservadora e
correta em princípio. Na prática, porém, o L293D perde cerca de 1,4 V internamente no transistor
superior, então a tensão que chega ao resistor é de aproximadamente 3,6 V:

```
I = (3,6 V - 2 V) / 180 Ω ≈ 8,9 mA
```

Ou seja, os LEDs vão acender com menos da metade da corrente pretendida. Ainda ficam visíveis, mas
bem mais fracos do que o projeto previa. Se o brilho for insuficiente na montagem, basta reduzir o
resistor para algo em torno de 82 ohms para voltar aos 20 mA. Registrado em
[P10](09-pendencias-e-roadmap.md).

Vale observar que usar um L293D para acender LEDs é um desperdício considerável de recurso: um CI de
16 pinos e quatro meias-pontes com diodos de proteção para acionar quatro LEDs. Um ULN2803, que tem
oito canais Darlington no mesmo tamanho, faria o serviço com metade dos CIs. Fica como sugestão de
otimização, não como erro.

## 3.9 Redes resistivas (RN1, RN2, RN3)

### O que são

Encapsulamentos SIP que agrupam oito resistores de mesmo valor com um terminal comum, referência
`RES8SIPB` no Proteus. Todas as três são de 10 kΩ.

### Como são usadas

RN3 é o pull-up das entradas de sensor. Ela puxa para 3,3 V as linhas dos sensores indutivos SI01 a
SI03 e das chaves CF09 e CF10, garantindo nível alto definido quando o sensor está em repouso e
protegendo o GPIO da Pi de tensões maiores.

RN1 e RN2 ficam entre as saídas dos PCF8574 e as entradas dos L293D. A razão é a característica
quase bidirecional da saída do PCF8574, que puxa firme para baixo mas conta apenas com 100
microampères para o nível alto. O pull-up externo firma esse nível e acelera a transição de subida.

### Por que rede em vez de resistores discretos

Onde há oito linhas precisando do mesmo resistor, uma rede SIP resolve com um componente e uma
solda, em vez de oito. Reduz espaço na placa, tempo de montagem e chance de erro.

---

Anterior: [02. Arquitetura de hardware](02-arquitetura-hardware.md) ·
Próximo: [04. Circuitos integrados](04-circuitos-integrados.md)

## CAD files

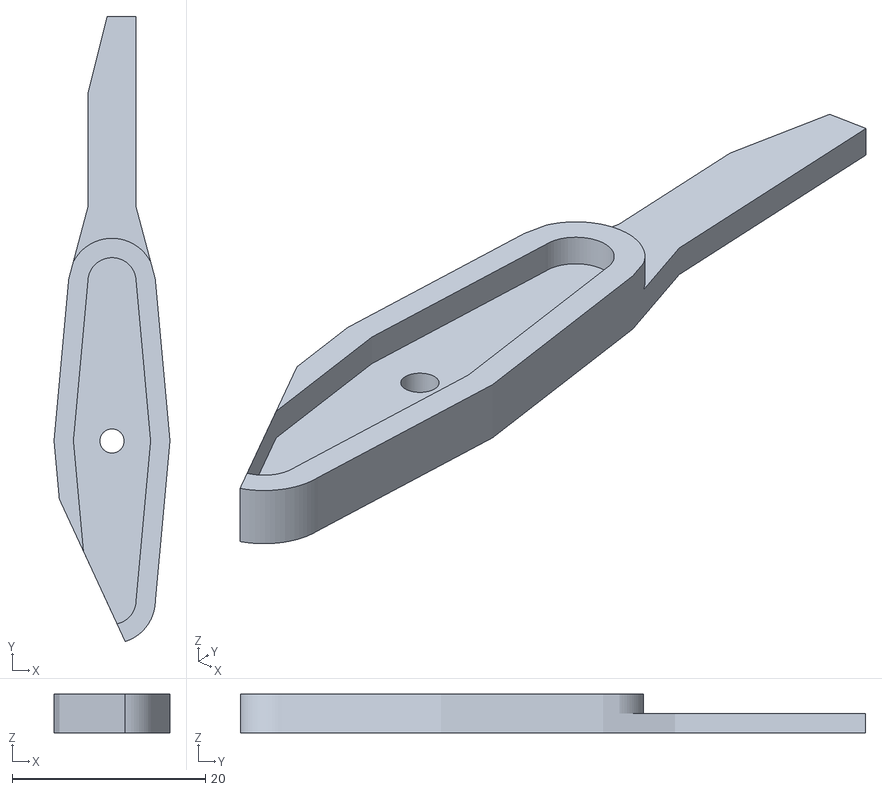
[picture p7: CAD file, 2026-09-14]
mecanica/modelos-3d/drop-target/print/servo_stick.stl
12.0 x 64.8 x 4.00

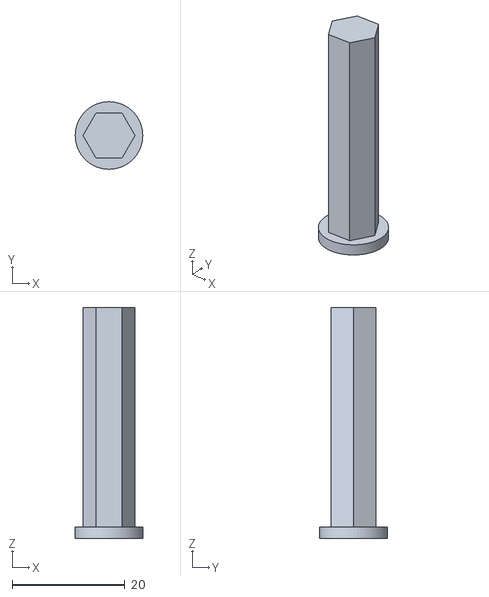
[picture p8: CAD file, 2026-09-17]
mecanica/modelos-3d/flipper/export/lado_direito/eixo.stl
12.0 x 12.0 x 41.0

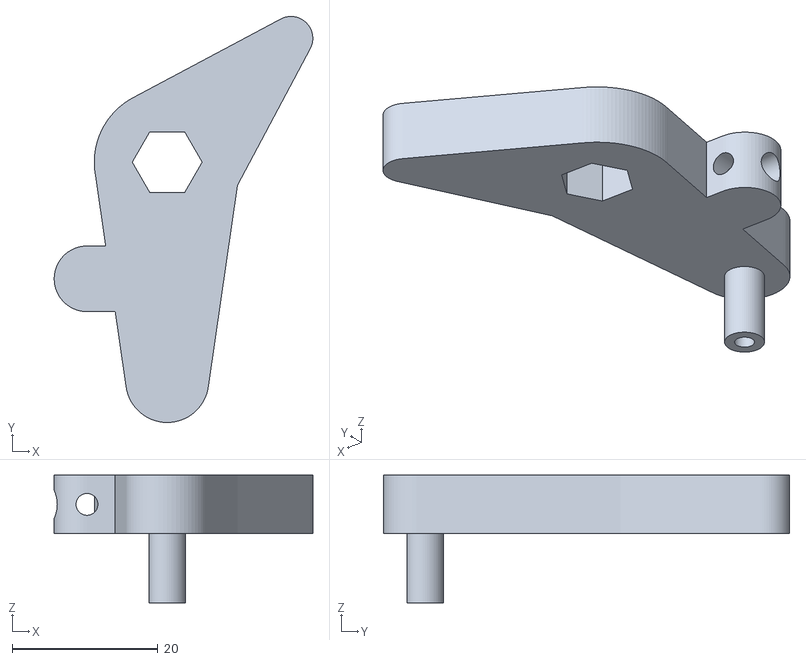
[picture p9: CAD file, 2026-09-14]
mecanica/modelos-3d/flipper/export/lado_esquerdo/alavanca.stl
35.5 x 55.7 x 17.5

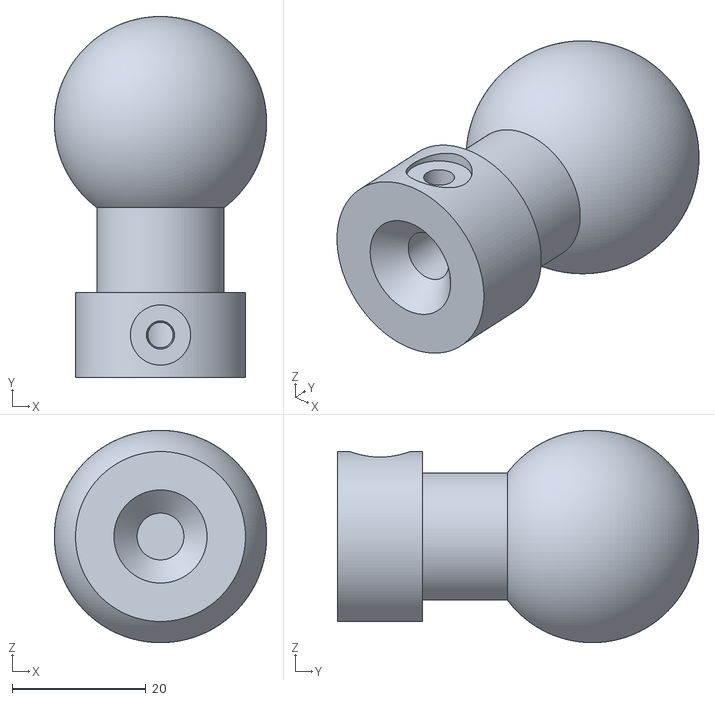
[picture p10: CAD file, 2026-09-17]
mecanica/modelos-3d/pinball-plunger/print/pinball-plunger-handle.stl
31.7 x 54.0 x 31.7

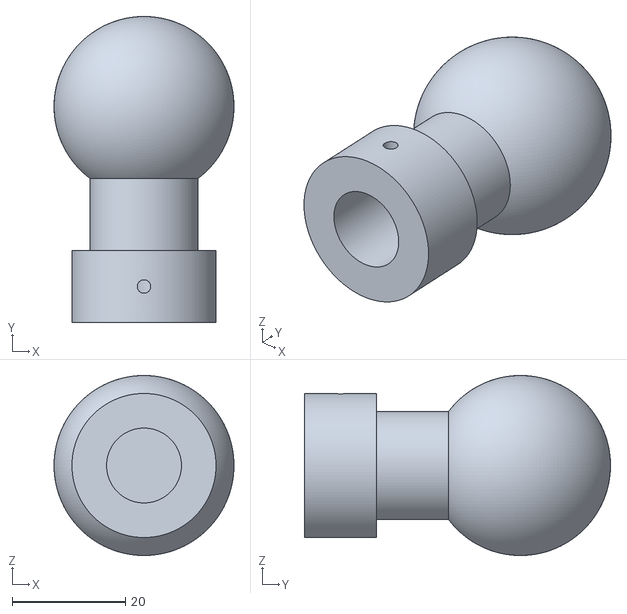
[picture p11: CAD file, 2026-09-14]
mecanica/modelos-3d/pinball-plunger/ref/Pinball_Plunger_Handle_v5.stl
31.7 x 54.0 x 31.7

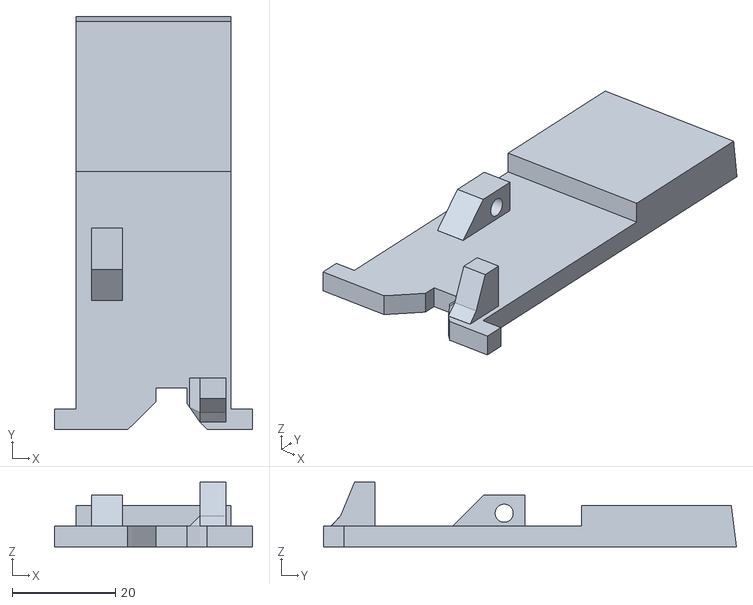
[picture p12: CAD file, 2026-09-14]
mecanica/modelos-3d/drop-target/print/target.stl
38.4 x 80.0 x 12.5

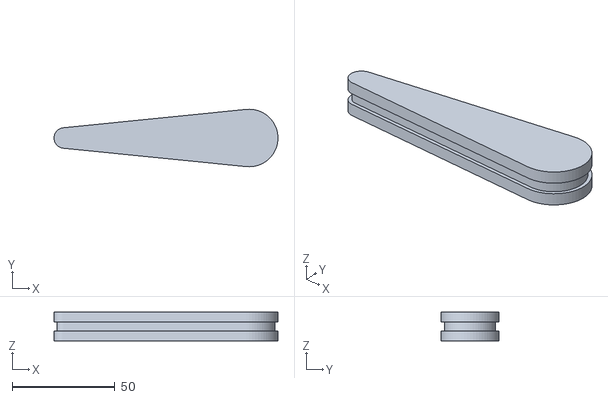
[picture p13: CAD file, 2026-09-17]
mecanica/modelos-3d/flipper/export/lado_direito/flipper.stl
109.0 x 28.0 x 14.0

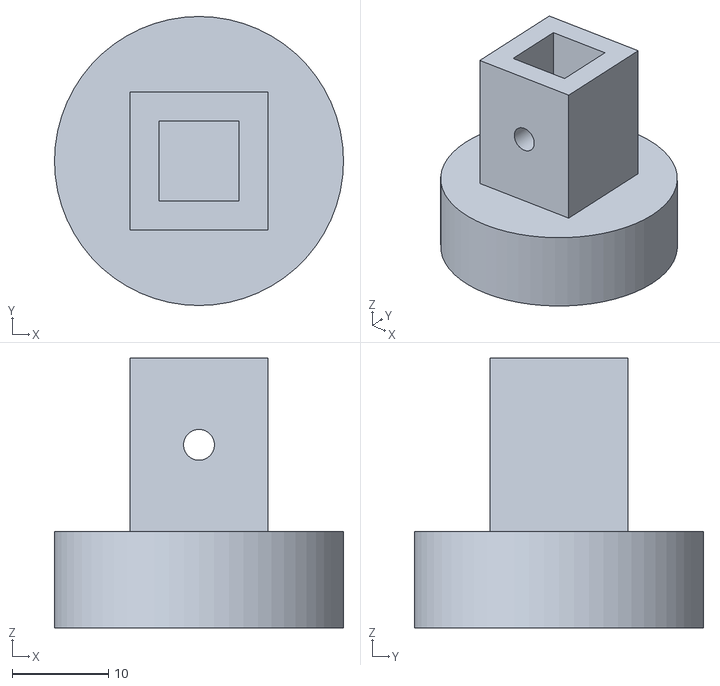
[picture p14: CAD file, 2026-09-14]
mecanica/modelos-3d/flipper/export/lado_esquerdo/botao.stl
30.0 x 30.0 x 28.0

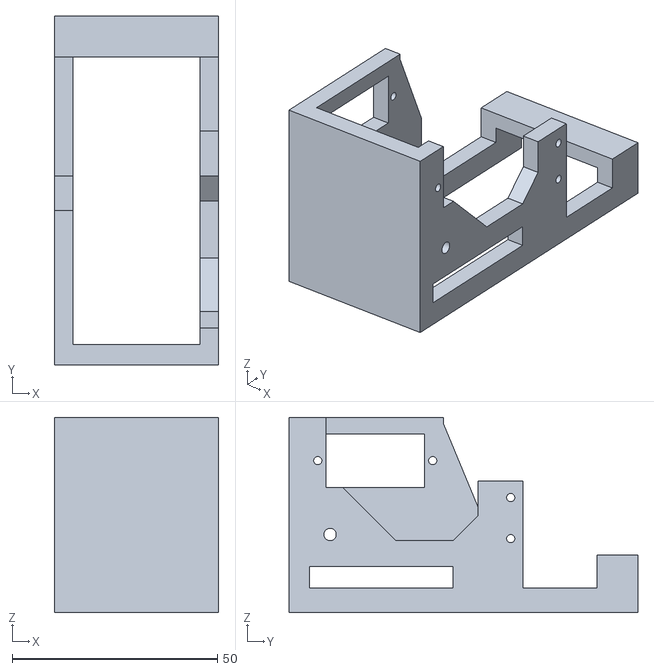
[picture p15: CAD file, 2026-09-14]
mecanica/modelos-3d/drop-target/print/cage.stl
40.0 x 85.0 x 47.5

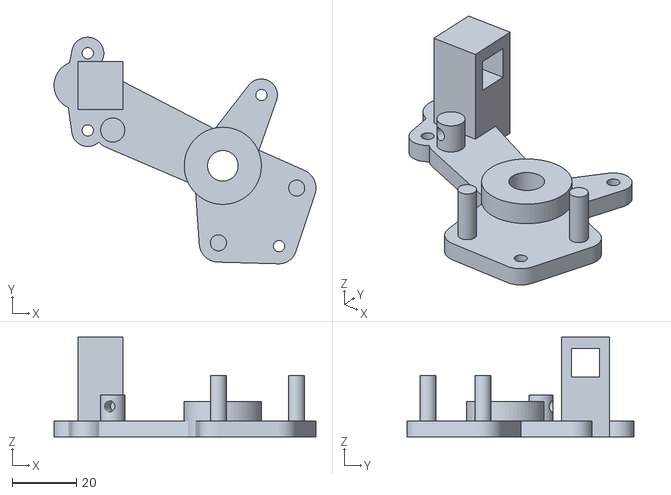
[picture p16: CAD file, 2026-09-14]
mecanica/modelos-3d/flipper/export/lado_esquerdo/base.stl
81.5 x 70.5 x 31.0

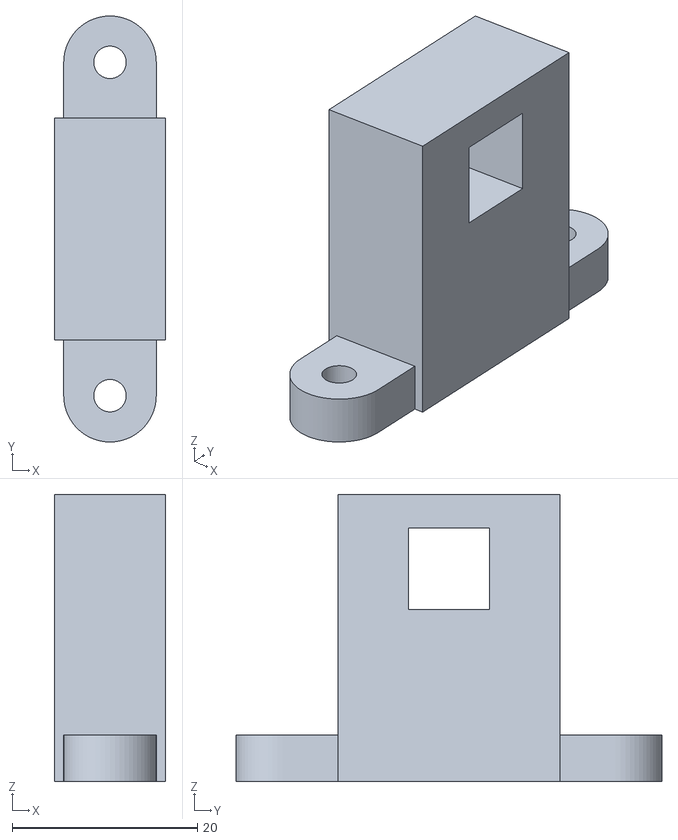
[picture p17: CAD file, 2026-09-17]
mecanica/modelos-3d/flipper/export/lado_direito/guia_frontal.stl
12.0 x 46.0 x 31.0

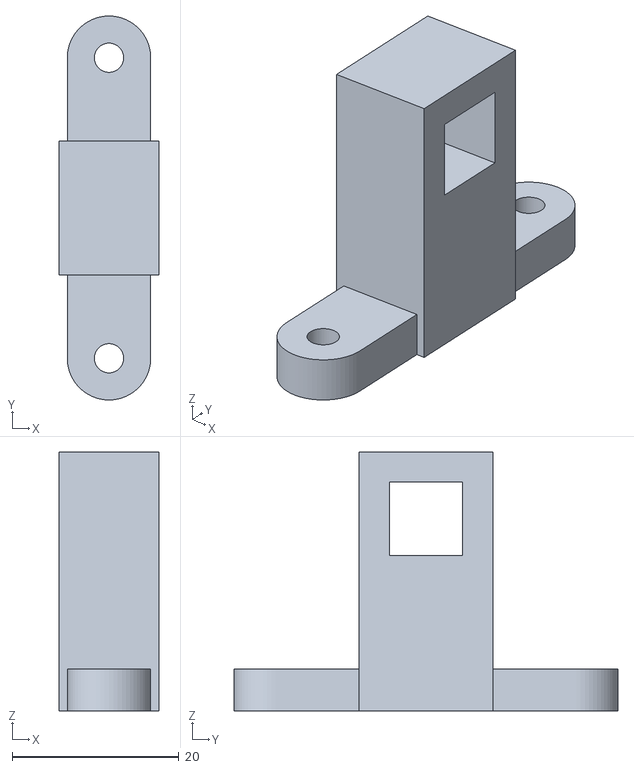
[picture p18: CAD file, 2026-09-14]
mecanica/modelos-3d/flipper/export/lado_esquerdo/guia_frontal.stl
12.0 x 46.0 x 31.0

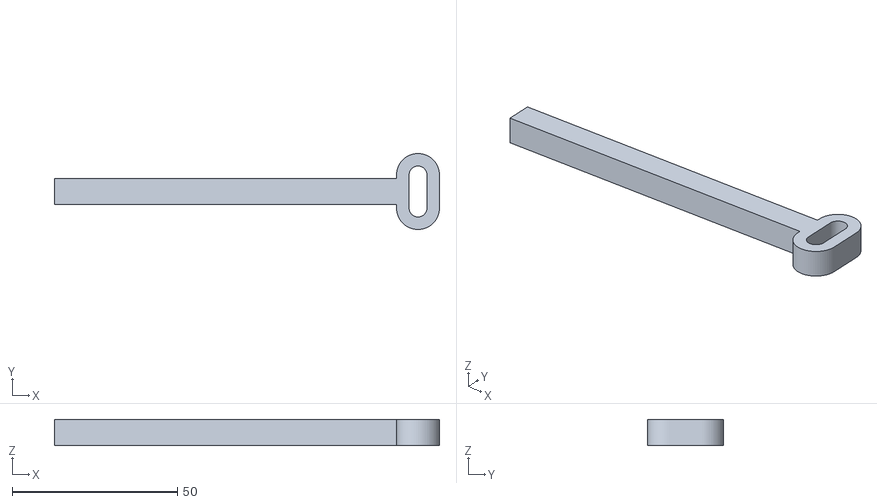
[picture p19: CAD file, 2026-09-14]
mecanica/modelos-3d/flipper/export/lado_esquerdo/haste.stl
116.5 x 23.0 x 8.00

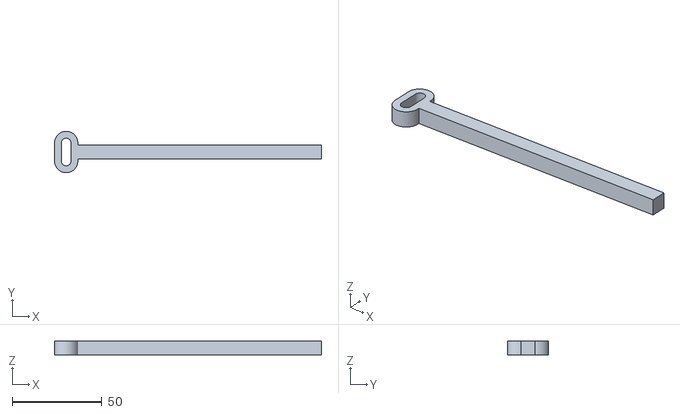
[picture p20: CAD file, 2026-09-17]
mecanica/modelos-3d/flipper/export/lado_direito/haste.stl
148.5 x 23.0 x 8.00

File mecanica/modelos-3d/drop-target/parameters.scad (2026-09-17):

// Parâmetros do drop target (milímetros).
//
// As três peças foram convertidas a partir dos STL em references/ e as
// medidas abaixo são as reais da malha. Alterar um valor aqui muda a peça
// no OpenSCAD; os STL originais continuam intactos como referência.

$fn = 64;
epsilon = 0.01;

// ---------------------------------------------------------------------------
// Quantidades e ajuste de tamanho peça a peça
// ---------------------------------------------------------------------------
// Esta etapa valida somente um módulo completo. A repetição fica para depois
// que a geometria e o curso forem aprovados no protótipo.
cage_count = 1;
target_count = 1;
servo_stick_count = 1;

// Escala independente por peça, no formato [X, Y, Z].
// [1, 1, 1] reproduz o STL original. Use, por exemplo,
// target_scale = [1, 1.2, 1] para deixar só o alvo mais comprido.
cage_scale = [1, 1, 1];
target_scale = [1, 1, 1];
servo_stick_scale = [1, 1, 1];

// ---------------------------------------------------------------------------
// Gaiola (cage.stl) — 40 × 85 × 47,5 mm
// ---------------------------------------------------------------------------
// Duas laterais idênticas em espessura, ligadas pela base e pela travessa
// frontal. O alvo desliza no vão entre elas.
cage_wall = 4.5;            // espessura de cada lateral
cage_bay_width = 40;        // passo entre gaiolas vizinhas no banco
cage_left_x = -5;           // face externa da lateral esquerda
cage_right_x = 30.5;        // face interna da lateral direita
cage_slot_width = 31;       // vão livre entre as laterais
cage_screw_diameter = 3;    // furo de fixação inferior
cage_pin_diameter = 2;      // furos de pino e do microswitch
cage_window = [[-77, 24.5], [-53, 37.5]];  // janela da lateral esquerda
cage_side_slot = [[-81, 0], [-46, 5.2]];   // fenda inferior das duas laterais

// Base e travessa atravessam a largura toda da gaiola.
cage_base_span = [-86, -81];   // faixa em Y ocupada pela base
cage_base_depth = [-6, 41.5];  // faixa em Z da base
cage_bar_span = [-11, -1];     // travessa frontal em Y
cage_bar_depth = [4, 8];       // travessa frontal em Z

// ---------------------------------------------------------------------------
// Alvo (target.stl) — 38,4 × 80 × 12,5 mm
// ---------------------------------------------------------------------------
target_width = 30;          // largura que desliza dentro da gaiola
target_length = 80;         // comprimento total (Y de -50 a 30)
target_plate_thickness = 4; // espessura da haste
target_head_height = 30;    // altura da cabeça visível (Y de 0 a 30)
target_head_thickness = 8;  // espessura da cabeça
target_head_draft = 1;      // recuo da face frontal ao longo da espessura
target_tab_width = 4.2;     // orelhas de retenção em cada lado
target_tab_span = [-50, -46];

// Bloco do laço, com furo passante para o fio.
target_knot_x = [3, 9];
target_knot_base_y = [-25, -11];
target_knot_top_y = [-19, -11];
target_knot_z = [4, 10];
target_knot_hole_diameter = 3.5;
target_knot_hole_center = [-15, 6.5];  // [Y, Z]

// Pino que aciona o microswitch.
target_pin_x = [24, 29];
target_pin_top_z = 12.5;

// ---------------------------------------------------------------------------
// Braço do servo (servo_stick.stl) — 12 × 64,8 × 4 mm
// ---------------------------------------------------------------------------
// O módulo já sai com o eixo do servo na origem.
servo_stick_hub = [75, 0];      // centro do eixo nas coordenadas do STL
servo_stick_lower_thickness = 2;
servo_stick_upper_thickness = 2;
servo_stick_shaft_diameter = 2.5;

// ---------------------------------------------------------------------------
// Montagem: como o alvo se aloja na gaiola
// ---------------------------------------------------------------------------
// A haste do alvo corre encostada na face traseira da gaiola (Z = -6) e as
// orelhas de 4,2 mm ficam atrás das laterais, prendendo o alvo contra a
// estrutura. Só a metade dianteira da cabeça entra no vão de 31 mm entre as
// laterais, e é ela que guia o alvo. Foi a única posição sem interferência em
// todo o curso, testada peça contra peça.
target_depth_offset = -10;

// Curso: baixado, a base do alvo encosta na base da gaiola e o topo da cabeça
// fica rente ao topo da estrutura (Y = -1); levantado, a cabeça aparece
// inteira. O curso é exatamente a altura da cabeça.
target_drop_offset = -31;
target_travel = target_head_height;

// ---------------------------------------------------------------------------
// Microservo SG90 (envelope de referência, não é peça impressa)
// ---------------------------------------------------------------------------
servo_body_length = 22.8;
servo_body_width = 12.2;
servo_body_height = 22.5;
servo_flange_length = 32.2;
servo_flange_thickness = 2.5;
servo_flange_z = 15.9;        // altura da aba medida a partir da base
servo_shaft_from_end = 5.9;   // distância do eixo até a ponta da carcaça
servo_boss_diameter = 11.8;
servo_boss_height = 4;
servo_shaft_diameter = 4.8;
servo_shaft_height = 7.5;
servo_horn_thickness = 2;
servo_horn_length = 38;       // braço plástico de duas pontas do SG90
servo_horn_end_diameter = 7;

// O servo fica baixo e à frente, próximo da lateral direita, mas dentro do
// envelope da gaiola. Com rotate([0, 90, 0]) o corpo ocupa o lado -X e a came
// sai pelo eixo +X em direção à alavanca.
// Origem: [X, Y, Z] no eixo de saída do SG90.
// Z = -5 deixa o corpo no plano frontal da gaiola depois da rotação da
// unidade; valores muito negativos projetam o servo para fora da estrutura.
servo_shaft = [23, -70, -5];
servo_cam_x = servo_shaft[0]
    + servo_shaft_height
    - servo_horn_thickness;
servo_cam_thickness = 4;
servo_cam_hub_diameter = 8;
servo_cam_lobe_diameter = 7;
servo_cam_lobe_length = 10;
servo_mount_depth = 20;
servo_mount_thickness = 4;
servo_mount_overlap = 1;

// ---------------------------------------------------------------------------
// Fio entre o braço e o alvo
// ---------------------------------------------------------------------------
// O fio é amarrado na ponta fina do braço e passa pelo furo do bloco do alvo.
// Com o fio esticado, o ângulo do servo define a altura do alvo: é assim que
// a simulação calcula o movimento.
// O fio é amarrado na ponta longa do braço, a aproximadamente 42 mm do eixo,
// e sobe até o furo do bloco do alvo. O comprimento permite que a ponta faça
// o arco necessário para os 30 mm de curso sem soltar o fio.
servo_stick_tie = [76, 42];   // ponto de amarração, coordenadas do STL
string_length = 38;
string_diameter = 1;
string_branch = -1;           // mantido para compatibilidade com a versão anterior

// ---------------------------------------------------------------------------
// Alavanca, micro-switch, came e retorno elástico
// ---------------------------------------------------------------------------
// Tudo permanece nas coordenadas da gaiola deitada; Y vira altura e Z vira
// profundidade quando a unidade é colocada em pé.
lever_pivot_x = 29.5;
lever_pivot_y = -76;
// A face frontal da gaiola está em torno de Z = -6. A alavanca fica logo à
// frente dela, e não dezenas de milímetros afastada.
lever_pivot_z = -14;
lever_length = 42;
lever_width = 5;
lever_thickness = 4;
lever_pivot_diameter = 6;
lever_pivot_axis_length = 9;
lever_rest_angle = -25;
lever_active_angle = 0;
lever_elastic_distance = 29;

// A came encosta na região do pivô e desloca a alavanca; ela não é uma união
// rígida entre o servo e a barra preta.
cam_release_sweep = 110;

// Ponto separado do bloco original do alvo para o elástico/barbante.
target_elastic_x = 17;
target_elastic_y = -18;
target_post_length = 4;
target_post_diameter = 3.5;
elastic_diameter = 1.4;

// Corpo centralizado e acionador voltado para a extremidade superior da barra.
switch_center_x = 21;
switch_center_y = -38;
switch_center_z = -17;
switch_body_size = [12, 14, 7];
switch_mount_band = 4;
switch_contact_x = 29.5;
switch_contact_y_pressed = -34.5;
switch_contact_z_pressed = -14;
switch_contact_y_free = -36;
switch_contact_z_free = -10;
switch_actuator_diameter = 1.8;
switch_roller_diameter = 3;
switch_press_threshold = 0.65;
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

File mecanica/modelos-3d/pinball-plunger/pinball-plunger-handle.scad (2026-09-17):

// Handle do plunger: corpo externo da referência com o encaixe interno
// refeito para a haste e o parafuso que vamos usar.
// Unidades: mm.
$fn = 96;
eps = 0.05;

reference_file = "ref/Pinball_Plunger_Handle_v5.stl";

// ---------------------------------------------------------------------------
// Medidas tiradas da malha de referência
// ---------------------------------------------------------------------------
// A referência é um desenho em polegadas: base de 1", pescoço de 3/4",
// envelope de 1 1/4", furo axial de 0,52" e furo de pino de 3/32".
axis_x = 1.371;             // eixo da haste
axis_z = -12.360;
front_y = 10.950;           // face de entrada da haste
base_diameter = 25.40;      // diâmetro externo da base
ref_bore_diameter = 13.21;  // furo axial original
ref_bore_end_y = 23.75;     // onde o furo original termina
screw_y = 17.300;           // centro do furo do parafuso, 6,35 mm da face

// Topo da base no plano do eixo: é por onde o parafuso entra.
top_surface_z = axis_z + base_diameter / 2;

// ---------------------------------------------------------------------------
// Haste
// ---------------------------------------------------------------------------
// Haste medida na peça real: 6,1 mm. A folga é generosa de propósito, porque
// furo em FDM sai menor que o nominal e a primeira impressão, com 6,0, não
// aceitou a haste.
rod_diameter = 6.1;
rod_clearance = 0.9;        // folga diametral, deixa o furo em 7,0 mm
rod_bore_diameter = rod_diameter + rod_clearance;
rod_bore_depth = 34.0;

// Chanfro de entrada: guia a haste e, de quebra, tira da face a borda do furo
// original de 13,21 mm, que é o que sujava a malha na boca do encaixe.
rod_lead_in_diameter = 14.0;
rod_lead_in_depth = 4.0;

// ---------------------------------------------------------------------------
// Parafuso de pressão
// ---------------------------------------------------------------------------
// O furo desce do topo da base até dentro do encaixe: a ponta do parafuso
// aperta a haste e é isso que prende as duas peças.
//
// O furo é cônico: entra com 4,2 mm no assento e fecha até 3,8 mm lá embaixo,
// junto ao encaixe da haste. O M4 começa a descer solto e vai apertando à
// medida que avança, até morder o plástico nas últimas voltas. Assim a partida
// é fácil, o esforço é progressivo e no fim existe aperto de verdade.
//
// A conicidade é suave: 0,4 mm em 7,8 mm de profundidade, pouco menos de 3° de
// ângulo incluso. O parafuso cruza a marca dos 4,0 mm na metade do caminho, e é
// dali para baixo que ele começa a abrir rosca.
screw_entry_diameter = 4.2;  // no fundo do assento
screw_end_diameter = 3.8;    // junto ao encaixe da haste

// Assento plano no topo. A base é cilíndrica, então sem ele a cabeça do
// parafuso apoiaria torta e a ponta escorregaria ao começar a entrar. Os 9 mm
// cobrem a cabeça de 8 mm de um M4 cabeça panela; com parafuso sem cabeça o
// assento só serve de guia.
screw_seat_diameter = 9.0;
screw_seat_depth = 0.6;

seat_edge_z = axis_z + sqrt(
    pow(base_diameter / 2, 2) - pow(screw_seat_diameter / 2, 2)
);
screw_seat_z = seat_edge_z - screw_seat_depth;

// Cotas derivadas. A haste é medida no pior caso: empurrada pelo parafuso, ela
// desce até o fundo do encaixe, e é dali que a ponta precisa alcançá-la.
bore_top_z = axis_z + rod_bore_diameter / 2;
rod_top_z = axis_z - rod_bore_diameter / 2 + rod_diameter;

// ---------------------------------------------------------------------------
// Peça
// ---------------------------------------------------------------------------
module reference_body() {
    import(reference_file);
}

// Tapa o furo axial original de 13,21 mm antes de abrir o encaixe novo. O
// cilindro é um pouco maior que o furo, para não sobrar casca entre os dois, e
// avança além do fundo do furo, onde já é material maciço.
module original_bore_fill() {
    translate([axis_x, front_y, axis_z])
        rotate([-90, 0, 0])
            cylinder(
                h = ref_bore_end_y - front_y + 1,
                d = ref_bore_diameter + 0.4
            );
}

// Encaixe da haste, com o chanfro de entrada.
module rod_bore() {
    translate([axis_x, front_y - eps, axis_z])
        rotate([-90, 0, 0]) {
            cylinder(h = rod_bore_depth + eps, d = rod_bore_diameter);

            cylinder(
                h = rod_lead_in_depth + eps,
                d1 = rod_lead_in_diameter,
                d2 = rod_bore_diameter
            );
        }
}

// Furo do parafuso: desce do topo da base e entra no encaixe da haste, senão
// a ponta não alcança. O furo original de 3/32" fica dentro deste.
module screw_hole() {
    // O corte passa do assento e do encaixe, então os diâmetros das pontas são
    // extrapolados para manter a conicidade exata entre os dois.
    taper = (screw_entry_diameter - screw_end_diameter)
        / (screw_seat_z - bore_top_z);
    cut_bottom_z = bore_top_z - 1;
    cut_top_z = top_surface_z + 1;

    translate([axis_x, screw_y, cut_bottom_z])
        cylinder(
            h = cut_top_z - cut_bottom_z,
            d1 = screw_end_diameter + (cut_bottom_z - bore_top_z) * taper,
            d2 = screw_end_diameter + (cut_top_z - bore_top_z) * taper
        );
}

module screw_seat() {
    translate([axis_x, screw_y, screw_seat_z])
        cylinder(
            h = top_surface_z - screw_seat_z + 1,
            d = screw_seat_diameter
        );
}

// Conferência das medidas do conjunto, impressa ao renderizar.
echo(str(
    "furo conico: ", screw_entry_diameter, " -> ", screw_end_diameter,
    " mm em ", screw_seat_z - bore_top_z,
    " mm | do assento ate a haste: ", screw_seat_z - rod_top_z,
    " mm (use parafuso mais longo que isso)"
));

difference() {
    union() {
        reference_body();
        original_bore_fill();
    }

    rod_bore();
    screw_hole();
    screw_seat();
}

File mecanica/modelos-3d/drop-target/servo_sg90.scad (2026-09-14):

include <parameters.scad>

// Envelope de referência de um microservo SG90 e do seu braço de plástico.
// Não é peça para imprimir: serve para conferir encaixe e curso.
//
// A origem fica no eixo de saída, sobre a face superior da carcaça, com o
// eixo apontando para +Z.

module servo_sg90(show_horn = true) {
    // Carcaça.
    color("royalblue")
        translate([
            -servo_shaft_from_end,
            -servo_body_width / 2,
            -servo_body_height
        ])
            cube([servo_body_length, servo_body_width, servo_body_height]);

    // Abas de fixação.
    color("royalblue")
        translate([
            -servo_shaft_from_end - (servo_flange_length - servo_body_length) / 2,
            -servo_body_width / 2,
            -servo_body_height + servo_flange_z
        ])
            cube([servo_flange_length, servo_body_width, servo_flange_thickness]);

    // Cubo e eixo estriado.
    color("white") cylinder(d = servo_boss_diameter, h = servo_boss_height);
    color("white")
        translate([0, 0, servo_shaft_height - servo_horn_thickness])
            cylinder(
                d = servo_shaft_diameter,
                h = servo_shaft_height - servo_boss_height
            );

    if (show_horn) servo_horn();
}

// Braço plástico de duas pontas que vem com o servo. Fica encaixado no
// rebaixo do servo_stick e gira junto com ele.
module servo_horn() {
    color("gainsboro")
        translate([0, 0, servo_shaft_height - servo_horn_thickness])
            linear_extrude(height = servo_horn_thickness)
                difference() {
                    hull() {
                        for (y = [-servo_horn_length / 2, servo_horn_length / 2])
                            translate([0, y])
                                circle(d = servo_horn_end_diameter);
                    }
                    circle(d = servo_shaft_diameter);
                }
}

// Microswitch preso na face interna da lateral direita da gaiola, nos dois
// furos que já existem na peça. A origem fica no meio dos dois furos, com o
// corpo avançando para dentro do vão (-X) e o comprimento em Z.
// pressed = true desenha a alavanca acionada pelo pino do alvo.
module microswitch(pressed = false) {
    angle = pressed ? switch_lever_pressed_angle : switch_lever_free_angle;

    color("black")
        translate([-switch_thickness, -switch_width / 2, -switch_length / 2])
            cube([switch_thickness, switch_width, switch_length]);

    // Terminais.
    color("silver")
        for (z = [-6, 0, 6])
            translate([-switch_thickness + 1, switch_width / 2, z - 1.5])
                cube([1.5, 4, 3]);

    // Alavanca articulada na ponta inferior, descendo até o dente do alvo.
    color("silver")
        translate([-switch_thickness / 2, -switch_width / 2, -switch_length / 2])
            rotate([angle, 0, 0])
                translate([-2, -switch_lever_length, -0.5])
                    cube([4, switch_lever_length, 0.6]);
}

servo_sg90();

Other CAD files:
mecanica/modelos-3d/flipper/export/lado_direito/botao.stl
mecanica/modelos-3d/flipper/export/lado_direito/base.stl
mecanica/modelos-3d/flipper/export/lado_direito/alavanca.stl
mecanica/modelos-3d/flipper/export/lado_esquerdo/eixo.stl
mecanica/modelos-3d/drop-target/servo_stick.scad
mecanica/modelos-3d/drop-target/cage.scad
mecanica/modelos-3d/drop-target/drop-target.scad
mecanica/modelos-3d/drop-target/references/cage.stl
mecanica/modelos-3d/drop-target/references/servo_stick.stl
mecanica/modelos-3d/drop-target/references/target.stl
mecanica/modelos-3d/drop-target/simulation/drop-target-simulation.scad
mecanica/modelos-3d/drop-target/target.scad
mecanica/modelos-3d/flipper/export/lado_esquerdo/flipper.stl
mecanica/modelos-3d/flipper/flipper-v5.scad

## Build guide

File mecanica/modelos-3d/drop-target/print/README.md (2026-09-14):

# Peças para impressão — drop target

Esta pasta contém uma unidade de cada peça imprimível da referência original.
Os arquivos estão em escala 1:1 e em milímetros.

| Arquivo | Peça | Envelope medido |
|---|---|---:|
| `cage.stl` | gaiola/estrutura | 40 × 85 × 47,5 mm |
| `target.stl` | alvo amarelo | 38,4 × 80 × 12,5 mm |
| `servo_stick.stl` | braço do servo | 12,02 × 64,79 × 4 mm |

O alvo completo mede 38,4 mm na largura por causa das abas de retenção. A cabeça visível mede
30 × 30 × 8 mm e é essa região que passa pela abertura do playfield.

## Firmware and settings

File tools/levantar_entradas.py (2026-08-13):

#!/usr/bin/env python3
"""
Levantamento do mapeamento sensor para GPIO.

Resolve a pendência P7: o esquemático não permite determinar qual sensor está
ligado a qual GPIO, porque os fios se cruzam sem rótulo de rede. Este programa
descobre isso na bancada.

São dois modos.

    python3 levantar_entradas.py monitor
        Fica imprimindo toda mudança de estado. Útil para conferir a fiação e
        para achar sensor com mau contato.

    python3 levantar_entradas.py identificar
        Pede para acionar um sensor por vez, na ordem da lista, e registra qual
        GPIO respondeu. No fim grava mapeamento.csv, pronto para preencher a
        tabela da seção 5.2 da documentação.

Depende de RPi.GPIO e roda na Raspberry Pi. Sem a biblioteca instalada:

    pip3 install RPi.GPIO
"""

import csv
import sys
import time

try:
    import RPi.GPIO as GPIO
except ImportError:
    print("RPi.GPIO não encontrado. Este programa roda na Raspberry Pi.")
    print("Instale com: pip3 install RPi.GPIO")
    sys.exit(1)


# Os 16 GPIOs configurados como entrada, iguais aos de src/components/Raspberry.py.
# A ordem aqui é numérica para facilitar a leitura da saída.
ENTRADAS = [4, 5, 6, 12, 13, 16, 17, 19, 20, 21, 22, 23, 24, 25, 26, 27]

# Número do pino físico no conector de 40 vias, para conferir com o multímetro.
PINO_FISICO = {
    4: 7, 5: 29, 6: 31, 12: 32, 13: 33, 16: 36, 17: 11, 19: 35,
    20: 38, 21: 40, 22: 15, 23: 16, 24: 18, 25: 22, 26: 37, 27: 13,
}

# Os 13 sensores do esquemático. A ordem é a da identificação.
SENSORES = [
    ("SI01", "Sensor indutivo"),
    ("SI02", "Sensor indutivo"),
    ("SI03", "Sensor indutivo"),
    ("CF01", "Fim de curso"),
    ("CF02", "Fim de curso"),
    ("CF03", "Fim de curso"),
    ("CF04", "Fim de curso"),
    ("CF05", "Fim de curso"),
    ("CF06", "Fim de curso"),
    ("CF07", "Fim de curso"),
    ("CF08", "Fim de curso"),
    ("CF09", "Fim de curso"),
    ("CF10", "Fim de curso"),
]

INTERVALO = 0.005  # 5 ms entre varreduras


def configurar():
    """Configura os pinos uma única vez, no início.

    Reconfigurar a cada leitura, como o scan() atual faz, solta o pull-up
    interno por um instante e pode gerar leitura falsa.
    """
    GPIO.setmode(GPIO.BCM)
    GPIO.setwarnings(False)
    for pino in ENTRADAS:
        GPIO.setup(pino, GPIO.IN, pull_up_down=GPIO.PUD_UP)


def ler():
    return {pino: GPIO.input(pino) for pino in ENTRADAS}


def descrever(pino, valor):
    estado = "ACIONADO" if valor == 0 else "liberado"
    return f"GPIO{pino:<2d} (pino físico {PINO_FISICO[pino]:>2d}): {estado}"


def monitor():
    """Imprime toda mudança de estado, indefinidamente."""
    print("Monitorando as 16 entradas. Ctrl+C para sair.\n")
    anterior = ler()

    em_repouso = [p for p, v in anterior.items() if v == 1]
    acionados = [p for p, v in anterior.items() if v == 0]
    print(f"Em repouso ({len(em_repouso)}): {em_repouso}")
    if acionados:
        print(f"Já acionados ({len(acionados)}): {acionados}")
        print("Entrada em nível baixo no repouso indica sensor preso, fio em")
        print("curto com o terra, ou pull-up ausente.")
    print()

    while True:
        atual = ler()
        for pino, valor in atual.items():
            if valor != anterior[pino]:
                print(descrever(pino, valor))
        anterior = atual
        time.sleep(INTERVALO)


def esperar_acionamento(referencia, tipo, base):
    """Espera um GPIO cair para nível baixo e devolve qual foi.

    Devolve None se o operador pular o sensor com Enter.
    """
    print(f"\n{referencia} ({tipo})")
    print("  Acione o sensor. Enter pula, Ctrl+C encerra.")

    while True:
        atual = ler()
        for pino in ENTRADAS:
            if atual[pino] == 0 and base[pino] == 1:
                print(f"  Respondeu: GPIO{pino}, pino físico {PINO_FISICO[pino]}")
                print("  Solte o sensor.")
                while ler()[pino] == 0:
                    time.sleep(INTERVALO)
                return pino

        # Enter pula o sensor atual, sem travar a varredura.
        import select
        if select.select([sys.stdin], [], [], 0)[0]:
            sys.stdin.readline()
            print("  Pulado.")
            return None

        time.sleep(INTERVALO)


def identificar():
    """Percorre a lista de sensores e registra qual GPIO responde a cada um."""
    print("Identificação de sensores.\n")
    print("Acione um sensor por vez, quando for pedido. No caso dos sensores")
    print("indutivos, aproxime a bola ou outra peça de metal da face.\n")

    base = ler()
    presos = [p for p, v in base.items() if v == 0]
    if presos:
        print(f"Atenção: já estão em nível baixo: {presos}")
        print("Esses pinos não serão detectados. Verifique antes de continuar.\n")

    mapeamento = {}
    usados = set()

    for referencia, tipo in SENSORES:
        pino = esperar_acionamento(referencia, tipo, base)
        if pino is None:
            mapeamento[referencia] = (None, tipo)
            continue
        if pino in usados:
            anterior = [r for r, (p, _) in mapeamento.items() if p == pino][0]
            print(f"  Atenção: GPIO{pino} já foi atribuído a {anterior}.")
            print("  Dois sensores no mesmo pino indica erro de fiação.")
        usados.add(pino)
        mapeamento[referencia] = (pino, tipo)

    resumo(mapeamento)
    gravar(mapeamento)


def resumo(mapeamento):
    print("\n" + "=" * 52)
    print("Resultado")
    print("=" * 52)
    print(f"{'Sensor':<8} {'Tipo':<17} {'GPIO':<7} {'Pino físico'}")
    print("-" * 52)
    for referencia, (pino, tipo) in mapeamento.items():
        if pino is None:
            print(f"{referencia:<8} {tipo:<17} {'-':<7} {'-'}")
        else:
            print(f"{referencia:<8} {tipo:<17} {'GPIO' + str(pino):<7} {PINO_FISICO[pino]}")

    atribuidos = {p for p, _ in mapeamento.values() if p is not None}
    livres = sorted(set(ENTRADAS) - atribuidos)
    print("-" * 52)
    print(f"Identificados: {len(atribuidos)} de {len(SENSORES)} sensores")
    print(f"GPIOs sem sensor: {livres}")
    if len(livres) != len(ENTRADAS) - len(SENSORES):
        print("O esperado eram 3 GPIOs de reserva. Divergência indica sensor")
        print("não identificado ou fiação diferente do esquemático.")


def gravar(mapeamento, caminho="mapeamento.csv"):
    with open(caminho, "w", newline="", encoding="utf-8") as f:
        escritor = csv.writer(f)
        escritor.writerow(["Sensor", "Tipo", "GPIO", "Pino fisico", "Funcao no jogo"])
        for referencia, (pino, tipo) in mapeamento.items():
            escritor.writerow([
                referencia,
                tipo,
                f"GPIO{pino}" if pino is not None else "",
                PINO_FISICO[pino] if pino is not None else "",
                "",  # preencher na montagem
            ])
    print(f"\nGravado em {caminho}.")
    print("Falta preencher a coluna de função no jogo, que só se define olhando")
    print("a mesa: qual é alvo, qual é botão de flipper, qual é o dreno.")


def main():
    modo = sys.argv[1] if len(sys.argv) > 1 else "monitor"
    if modo not in ("monitor", "identificar"):
        print(__doc__)
        sys.exit(1)

    configurar()
    try:
        monitor() if modo == "monitor" else identificar()
    except KeyboardInterrupt:
        print("\nEncerrado.")
    finally:
        GPIO.cleanup()


if __name__ == "__main__":
    main()

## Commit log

2026-08-06 Add technical documentation for the pinball project
    Document the hardware, software and mechanical work delivered by the
    previous team, which had no usable documentation.
    Contents:
    - Component reference covering every part in the schematic, with the
    role each one plays in the machine
    - Datasheet-level detail on the PCF8574 I/O expander and L293D driver
    - Complete pin-by-pin I/O maps for the Raspberry Pi and both ICs
    - Software walkthrough of the Raspberry and Pcf8574 classes
    - Proteus simulation notes and its limits
    - Known issues and roadmap, including a critical I2C address conflict
    where all three PCF8574 share address 0x20, the likely root cause of
    the intermittent bus failures re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
2026-08-06 Adjust semester plan to the confirmed class calendar
    The Monday session of 10/08 was cancelled and the semester now ends on
    11/12, which removes the 14/12 and 17/12 meetings. Useful meetings drop
    from 28 to 25, the last one being Thursday 10/12.
    - Renumber every meeting and each sprint's meeting range
    - Flag Sprint 0 as short: only 06/08 and 13/08 remain, so reading the
    docs and contacting the previous team should happen outside class
    - Flag Sprint 5 as tight: four meetings for assembly, calibration,
    playtesting and the final report, with no room for mechanical rework
    - Move the Sprint 4 and Sprint 5 milestones to the Mondays that still
    exist, and reserve 10/12 for delivery rather tha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
2026-08-06 Fix Monday cadence and reflect work done on 06/08
    Mondays run fortnightly from 17/08, not 10/08, which shifts every Monday
    in the semester: 31/08, 14/09, 28/09, 12/10 (holiday), 26/10, 09/11,
    23/11 and 07/12. Only one holiday now lands on a meeting, so useful
    meetings go back up to 27.
    The 06/08 meeting went into organising the project, writing the technical
    documentation and setting up the activity board, so technical survey work
    starts on 13/08. Sprint 0 is renamed accordingly and its first item is
    marked done.
    - Renumber every meeting and each sprint's range
    - Move all Monday milestones onto Mondays that exist
    - Move the power-stage review to Thursday 08/10, since the Monday in that
    w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
2026-08-13 Add input survey tool and Sprint 0 field form
    The sensor-to-GPIO mapping cannot be read from the schematic: wires cross
    without net labels and the Proteus DSN is a binary format with no textual
    netlist. It has to be surveyed, and it blocks the game logic.
    - tools/levantar_entradas.py surveys it on the bench. Monitor mode prints
    every state change; identify mode prompts for one sensor at a time,
    records which GPIO answered and writes mapeamento.csv. It configures the
    pins once instead of on every scan, avoiding the false readings the
    current scan() can produce, and warns on duplicate or stuck pins.
    - docs/11-ficha-de-levantamento.md is the form to fill in during the 13/08
    and 17/08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
    [levantar_entradas.py]
2026-08-13 Record decision to redesign the circuit from scratch
    A photo of the table taken on 13/08 shows the cabinet and the decorated
    playfield are built, with ball guides and mounting holes in place, but no
    electronics at all: no sensor, solenoid, LED, wire or board is installed.
    The previous team's circuit never left paper.
    That removes the reason to reverse-engineer the old schematic. With no
    wiring to preserve, the sensor-to-GPIO mapping stops being something to
    discover and becomes something to decide, which unblocks the schedule.
    - docs/12-projeto-novo-do-circuito.md records the decision, what is still
    worth keeping from the previous work, and the order to follow: playfield
    map, I/O count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
2026-08-13 Revise sprints 0 to 2 for the redesign decision
    Sprint 0 stopped being a survey of the old schematic and became a survey
    of the physical table: map the playfield, decide the game scope, count
    the I/O. Sprint 1 stopped being about fixing the old schematic and became
    drawing the new one plus closing the bill of materials.
    Sprint 2 no longer quotes the previous project's quantities, since how
    many sensors, expanders and lights exist now comes from the new design.
2026-08-13 Add playfield design guide
    The circuit follows from the playfield, and the playfield had no guidance
    at all. This covers designing the game itself: ball paths, what each
    element does, what makes a layout fun, and the rules.
    Starts from rolling the ball on the actual table, since the cabinet and
    the holes already exist, and that reveals the natural paths no drawing
    would. Recommends Inkscape over a top-down photo for the scale drawing,
    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
2026-08-13 Add scaled playfield template for the measured 450 x 900 mm table
    The cabinet measures 450 x 900 mm, which is about 86 percent of a
    commercial Williams playfield (515 x 1067 mm), so commercial proportions
    scale across almost directly instead of needing a redesign.
    - Record the scaled figures: 65 mm flippers, 153 mm between pivots for a
    40 mm gap, pivots 90 mm from the bottom, and 95 to 111 mm of drop
    depending on the 6 to 7 degree incline
    - tools/gerar_gabarito_playfield.py generates a 1:1 SVG template with a
    10 mm grid, the three zones, flippers at rest with the gap and the ball
    drawn to scale, and an empty 'proposta' layer to draw on. It opens in
    Inkscape at true physical size a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
2026-08-13 Reorder the semester to build mechanisms before drawing
    The plan now works bottom-up. Instead of designing the playfield and the
    circuit on paper and building afterwards, the semester starts by making
    the most critical mechanism actually work: driving a solenoid hard enough
    to throw the ball in a way that suits the table.
    The reasoning is that the force needed, the peak current and the right
    pulse length can only be found by experiment, and those three numbers are
    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
2026-08-13 Trim the field form to what Sprint 0 now needs
    With Sprint 0 becoming preparation for the bumper prototype, the sections
    on sensor mapping, mechanical inventory, Proteus simulation and contacting
    the previous team no longer belong here. They return when their sprints
    arrive.
    What is left is the hardware inventory, now focused on the prototype's
    bill of parts, plus the measurements the prototype depends on: usable
    playfield area, ball diameter and working incline. Without the last two
    there is no way to tell whether the bumper's throw makes sense.
2026-08-13 Keep only the documentation of what already exists
    Remove the planning material I had added: the semester plan, the field
    form, the redesign decision doc and the playfield template generator. The
    repository goes back to documenting the previous team's work, which is
    what it is for.
    The photo of the table stays, moved into the README's current-state
    section, since what it shows is a fact about the project: the cabinet and
    decorated playfield are built, the cabinet measures 450 x 900 mm, and no
    electronics are installed.
    Docs 01 to 09 are untouched. Planning now lives in the Notion board.
2026-09-03 README and 3d models
    [cage.scad, cage.stl, flipper.scad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]
2026-09-03 Drop Target
    [base.scad, cage.scad, drop-target.scad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]
2026-09-03 Primeira versão do flipper para impressão
    [alavanca.stl, base.stl, eixo.stl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]
2026-09-10 Nova versão da haste dividida em duas peças.
    [flipper-v3.scad]
2026-09-10 Drop target simulation and file to print
    [base.scad, cage.scad, cage.stl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]
2026-09-10 Complete simulation
    [drop-target-simulation.scad]
2026-09-14 Inserção de suportes para segurar a haste da alavanca do flipper
    [flipper-v3.scad]
2026-09-14 Versão final do flipper lado esquerdo
    [alavanca.stl, base.stl, botao.stl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]
2026-09-16 Plunger handler works
    [pinball-plunger-handle.scad, pinball-plunger-handle.stl]
2026-09-17 Versão final do flipper com possibilidade de alternar entre lado esquerdo e direito
    [alavanca.stl, base.stl, botao.stl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]
2026-09-17 Taper the plunger screw hole from 4.2 to 3.8 mm
    The straight hole either gripped nothing at 4.0 mm or needed too much
    torque at 3.5 mm. The taper starts loose and tightens as the screw goes
    in, reaching 0.1 mm of interference at the bore.
    Also widens the rod bore to 7.0 mm for the 6.1 mm rod measured on the
    real part, and records every hole version tried and why it was dropped.
    [pinball-plunger-handle.scad, pinball-plunger-handle.stl]
2026-09-17 Restore the drop target conversion dropped by the merge
    Merge 7ac8b92 brought back the old invented model over the parts
    converted from the reference STLs. That left the folder inconsistent:
    the committed simulation and print files expect the converted
    parameters, so drop-target-simulation.scad failed with 111 undefined
    variable warnings.
    Restores parameters, cage, target, servo_stick, drop-target and the
    README from 6316134, and drops base.scad again. Both drop-target.scad
    and the simulation now render without warnings.
    [base.scad, cage.scad, drop-target.scad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]
2026-09-17 Update the 3D models index
    Lists the three mechanisms with their current state, the flipper view
    modes and exported parts, the drop target envelopes and simulation, and
    the plunger. Adds the command line export and a note on FDM hole
    shrinkage, which is what ruined the first plunger print.
2026-09-17 Cover the flipper v5 in the models index
    The v5 file handles both sides through lado_flipper, which also adjusts
    the lateral distance, the rod travel and the guide position, and the
    exported parts are now split per side.
2026-09-17 Bring the flipper section up to date in the models index
    The index pointed at flipper-v4-esquerdo.scad, deleted in 462767c, and
    did not cover the flipper and eixo view modes added in 5b0a942. Lists
    the seven part modes, notes that the print bed mode leaves two of them
    out, and records the guide position among the measures lado_flipper
    switches.
2026-10-21 Add the launcher cylinder and housing
    The cylinder sits inside the playfield and is the face the ball rests
    against; the housing bolts to the outside of the cabinet wall and holds
    the spring.
    Both parts derive their dimensions from a single constraint: the
    cylinder must travel exactly as far as it protrudes into the playfield,
    30 mm. Travel less and the ball does not fit in front of it; travel
    more and the wall hole opens and the ball drops in. A 45 degree cone
    inside the housing stops it at that point, mating with the chamfer on
    the cylinder face.
    The spring sits whole between the two, held by a raised ring on the
    cylinder face and a shallow seat in the housing end cap.
    The plate holes a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
2026-11-05 Add the drop target servo bring-up script
2026-11-05 Stop requiring pigpio for the drop target servo
    Installing pigpio fails on the Pi with "no installation candidate", so the
    README sent people to a dead command. pigpio is not needed: gpiozero picks
    whatever backend is present, and lgpio is the current default on Raspberry
    Pi OS. It jitters a little under load but is fine for an arm that only moves
    now and then, and the script detaches the servo afterwards anyway.
    The script now reports which backend it ended up on instead of only warning
    that pigpio is missing, and the fallback no longer raises on its way out when
    gpiozero cannot name a pin factory.
    Move the servo ground to physical pin 14, next to the signal on pin 12, so
    there is only on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
2026-11-09 Restore the servo pin to BCM 18
    gpiozero takes BCM numbers, not header hole numbers, and the two differ:
    BCM 18 is hole 12, while BCM 12 is hole 32. Setting the constant to 12 left
    the wire in the right hole but drove a different pin, so the servo stayed
    still without raising anything.
    Name both numbers next to the constant, say so in the comment, and print the
    pair at startup, so the two never have to be held in your head at once.
2026-11-09 Say plainly that pigpio is gone, and stop telling people to install it
    Raspberry Pi OS dropped pigpio in Trixie: Debian removed it in 2025 because
    upstream is unmaintained and it does not work on the Pi 5. apt answers "no
    installation candidate" and no amount of apt update changes that, so the
    README was sending people into a wall it called optional.
    Nothing needs to change to run: gpiozero falls back to lgpio, whose pulse
    jitters a little under load but is fine for an arm that moves now and then,
    and the script detaches the servo afterwards anyway. Point the upgrade path
    at the SoC hardware PWM through a dtoverlay instead, which is what replaced
    pigpio, and keep the pigpio attempt in code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
2026-11-09 Add a C version of the servo test driven by the SoC hardware PWM
    C on its own buys nothing here: the Python path already spends its time in
    the kernel, and a C program calling the same library would jitter the same
    way. What removes the jitter is moving the pulse off the CPU, so this talks
    to the SoC PWM block through /sys/class/pwm and lets the silicon keep time.
    That needs no library at all beyond libc.
    It takes the same arguments and the same pulse limits as the Python version,
    so the two can be compared directly. It costs a dtoverlay, a reboot and root,
    which is why the Python one stays the place to start.
    The pwmchip number moves between kernels and board models, so the chip is
    search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
2026-11-09 Let the two servo angles be set independently, and add a calibration mode
    The lift angle was computed as the rest angle plus the 75 degrees the
    mechanical simulation calls for. That looked tidy and got in the way: it tied
    both values to a travel that may not be yours, and it ruled out the case
    where lifting means a smaller angle, which depends on where the horn ended up
    pointing. Both are plain constants now, and the program prints the resulting
    travel and says so when it strays far from the simulation, since a travel way
    off usually means the horn sat on the wrong spline.
    --calibra moves on each angle typed, holding the pulse between moves so the
    arm stays where it was put and can be looke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
2026-11-09 Set the servo angles measured on the bench, and drop the Python version
    Rest sits at 54 degrees and lift at 97, both read off the arm with the cage
    and target assembled. That is 43 degrees of travel where the mechanical
    simulation called for 75. The real part wins, and the sanity check now
    compares against the measured travel instead of the simulated one, so it
    still catches a horn fitted on the wrong spline without crying wolf on every
    run. Some of the gap is only a matter of reference, but 32 degrees is a lot
    for that alone, and the simulation's arm geometry is worth a look before the
    assembly is repeated three times.
    The Python version is gone. An earlier commit of mine took it out witho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
2026-11-09 Bring the arm back to rest after it lifts the target
    Leaving the arm up blocks the target: the ball cannot knock it down again
    while the arm is standing in its way. The cycle only closes once the arm is
    back underneath, ready for the next hit, so the run now goes rest, lift,
    pause, rest.
    The pause gives the target time to settle onto the cage catch before it loses
    the arm beneath it. A target that drops by itself right after being raised
    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
2026-11-12 Bring the drop target README back in line with the code
    Several sections still described the Python version and the choices made
    before the driver moved to the SoC PWM:
    The device tree overlay was filed under "if the jitter bothers you". It is
    not optional any more: without it the PWM block never appears under
    /sys/class/pwm and the program has nothing to talk to. It also appeared
    twice, and the copy under the build instructions was missing the [all]
    header, which is the one detail that decides whether the line applies at all.
    The install section opened by saying gpiozero ships with the OS and then told
    you no library is needed, left over from an edit that replaced the commands
    but not the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
2026-11-12 Zero the duty cycle before setting the period
    The kernel refuses a period shorter than the channel's current duty cycle,
    and that duty cycle is whatever the last user of the channel left behind,
    which may well be another program or a slow blink test typed by hand. Writing
    the period first then fails with EINVAL and the run dies having done nothing.
    Writing zero to the duty cycle is always accepted, so doing that first makes
    the program independent of the state it finds.
    When the period write still fails with EINVAL, say what it usually means and
    give the two commands that clear the channel, since the message on its own
    says nothing about which of the two values is the problem.
    Also record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
2026-11-12 Raise the drop target when the switch reports it fell
    drop_target watches the limit switch and runs the arm: the ball knocks the
    target down and closes the switch, it waits two seconds for the ball to clear,
    lifts the target onto the cage catch, then pulls the arm back out of the way.
    The switch sits between ground and BCM23, with no resistor: the kernel turns
    on the pin's own pull-up, so the line idles high and is pulled down when the
    target falls. The trigger is the falling edge rather than the level, because a
    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
2026-11-12 Trigger on the switch opening, which is how the cage actually works
    The standing target holds the lever down, so a fall releases the switch
    rather than pressing it: the line idles low and rises when the target drops.
    The program was watching for the opposite edge and so never fired. Since all
    three cages will be built the same way, this is the default now, with
    --chave-solta-em-pe for the other arrangement.
    On startup it reads the line and prints the level alongside the arrangement
    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
2026-11-12 Raise a fallen target at startup before listening for the next one
    The trigger is an edge, and a target sitting at the bottom produces none, so
    a game that ended with one knocked down would start the next with a dead
    target that nothing would ever raise. The program now reads the switch on
    startup and runs the arm first when it finds the target already down.
    After arming it reads the switch again. If the arm moved and the switch did
    not change, it says so and names the three things that cause it: the target
    not catching on the cage, the switch not being worked by the target, or the
    arrangement being the other way round. Without that the failure looks exactly
    like a target that is simply nev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
